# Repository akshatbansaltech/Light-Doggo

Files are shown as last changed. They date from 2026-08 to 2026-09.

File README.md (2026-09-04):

# Light Doggo

Light Doggo is a DIY quadruped robot using 'low cost' BLDC motors.

## Basic Specifications

* RPi 5
* 12x BLDC motors
* Auxiliary board w/LCD display
* 9-axis accelerometer/gyro sensor
* 6s Li-Ion battery, ~72wH

Light Doggo's control system is coded in Python.

# Docs

See the docs directory for a setup guide, bill of materials (BOM), 3D printed parts info, and miscellaneous design notes.

# Development Journal

For a detailed development log with images, see [JOURNAL.md](JOURNAL.md).

# UI

The UI shows the status of the entire system: quadruped joint positions, subsystem status, motor information, inputs, sensors, loop times, etc. The above image shows the simulated quadruped overlapped with real quadruped (based on motor feedback).

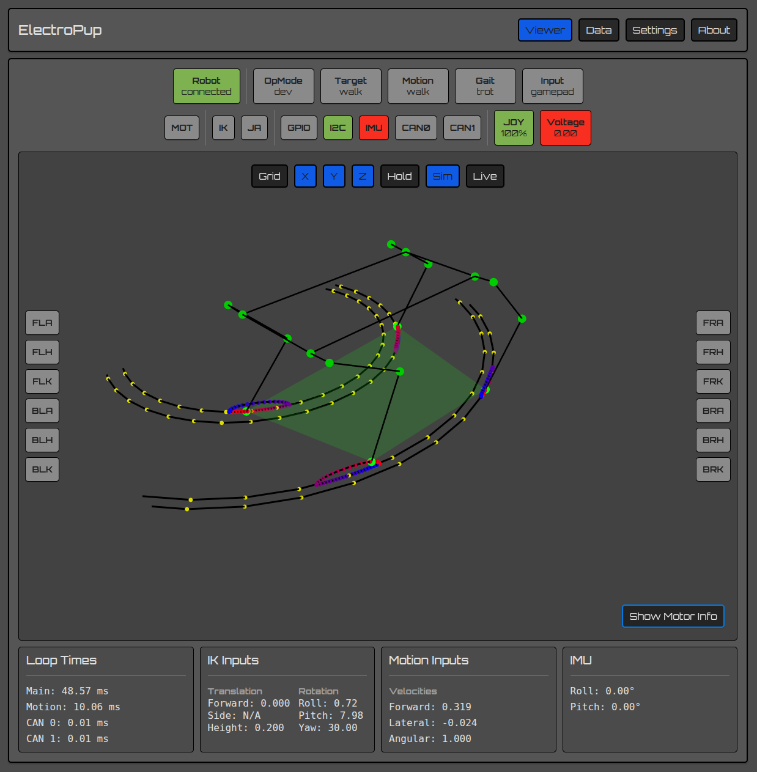
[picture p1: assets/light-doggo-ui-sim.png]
ElectroPup UI Simulation


The above image shows a virtual circle the feet follow to walk in a circle and the bezier curves used for moving the feet up and down.

The UI is built from the React Native Framework using Expo and runs on web. The app will run on Android without the plot. The entire system runs in dev mode so you can run the simulation and UI from a development PC without physical hardware.

# Kinematics

Inverse kinematics, leg position, and gamepad inputs are verified using the UI.

### Trajectories

Bezier curves, sin arcs, and curvature projection are used to generate trajectories. The plots below are examples of control points configurations.

The output of `./src/plot/bezier_curve_plot.py`

Rotation is achieved by projecting a linear trajectory onto a curve. The plots are of example projection calculations.

The output of `./src/plot/projection_plot.py`

# Simulation

Simulation is performed in MuJoCo and can be started by running `./src/sim.sh`. Currently, input controlls are only provided by the gamepad.

The `ElectroPup.xml` currently does not have approximate masses or inertial so the simulated quadruped is rather bouncy.

# Electronics

## PCBs

PCBs are designed in KiCad v8(is compatible with KiCad v10 or higher).

### Power Carrier

The Power Carrier PCB provides a main on/off power switch and distributes power to the motor headers. The Power Carrier creates four CAN bus networks one for each leg. Solder jumpers allow merging the front two legs into a single network and the back two legs into another single network.

### Auxiliary Board

The auxiliary board is optional and not required for the quadruped to operate.

Features:

* Powers RPi via terminal header
* LCD display
* Buzzer (variable pitch)
* NeoPixel strips
* RC Servo channel
* I2C expansion
* Button to control LCD and shutdown Raspberry Pi before power off

Provides direct connection to RPi header for the following breakouts:

* IMU (BNO055 via I2C)
* 4x contact inputs or GPIO
* I2S for sound driver (future barks)
* SBUS to use RC transmitter if BLE gamepad fails in RF congested areas

# Software Architecture

Electropup's software architecture was purposely designed to be simple and to bypass the pain points of using ROS2. A major downside of this single service architecture is needing to sit and stand the quadruped on every software change vs being able to restart individual services quickly without affecting others (i.e. the motors). However, with the simulated quadruped and UI, most development is not performed on a live quadruped.

# Motors

The motors are MG4010E-i10v3 actuators made by LingKong (LKMTECH).

### Specifications

* voltage: 7.4-32V
* communication: CAN 1Mbps
* rated torque: 2.5 N.m
* max torque: 4.5 N.m
* rated current: 3.5 A
* max power: 140 W
* gear ratio: 1:10
* encoders: 18-bit motor, 14-bit reducer
* size: 53mm diameter, 41mm tall

### MG4010E-i10v3 Pros

* easy to use configuration software over non-proprietary USB to UART hardware
* readable CAN bus communication documentation
* small physical size that works well with the desired frame size of ElectroPup
* non-proprietary power/communications connector (JST-ZH 6-POS)

### MG4010E-i10v3 Cons

* configuration software is Windows only
* closed source firmware
* foreign sourced, complicating the warranty process
* CAN unable to configure all parameters
* UART required to configure error thresholds, motor torque limits (for compliance), etc.
* some motors are more difficult to turn by hand and require slightly more operational current

Future projects will prioritize ODrive compatible drivers.

### Motor Zero Positions

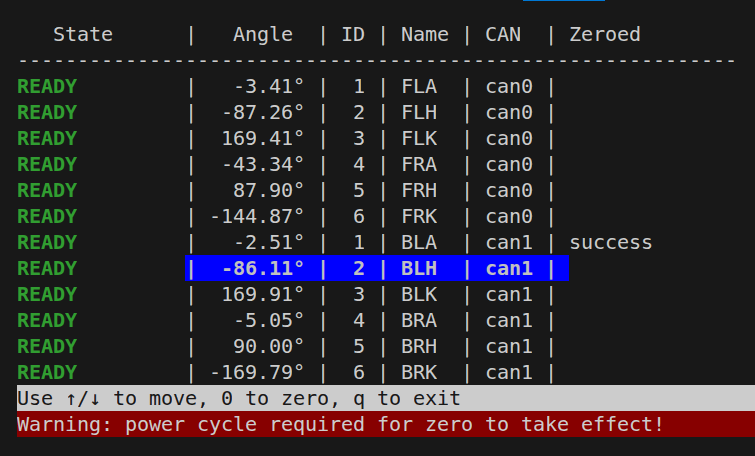
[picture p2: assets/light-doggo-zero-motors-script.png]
Motor Zero Positions


### Motor Tags

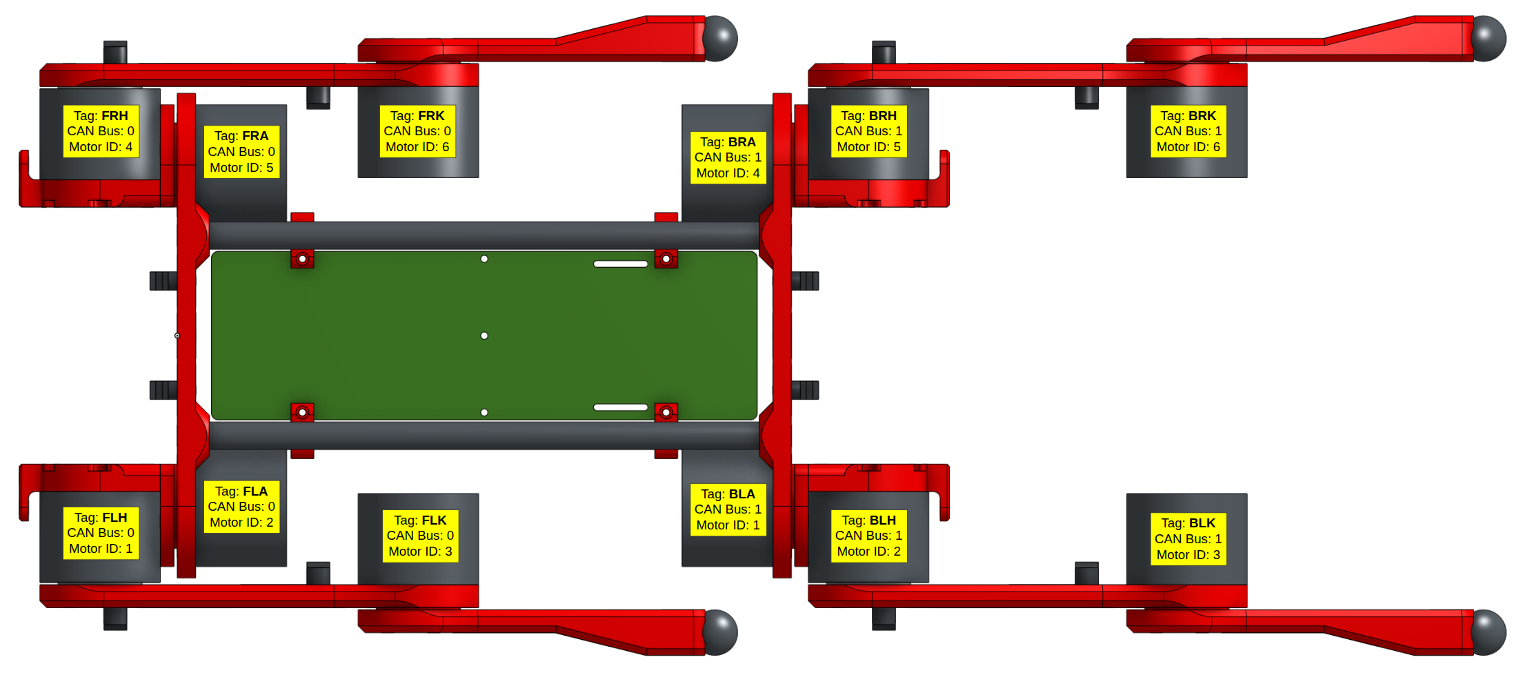
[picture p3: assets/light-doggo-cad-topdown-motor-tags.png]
Motor Tags


### Motor Calibration

The zero-motors.py script is a quick way to verify correct motor configuration and to zero the motors.

Motor Calibration

# CAN Bus

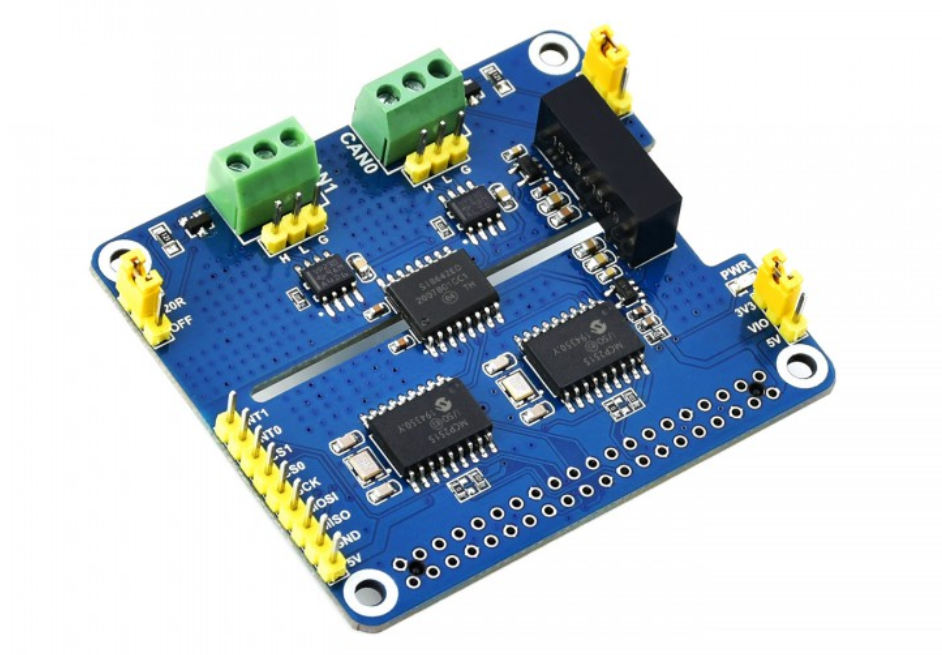
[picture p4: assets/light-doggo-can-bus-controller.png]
CAN Bus Controller


The CAN bus controller is a 2-Channel Isolated CAN Expansion HAT from waveshare.

Each CAN controller drives six motors with an average motor update rate of ~70 Hz. This includes fetching encoder position, setting target angle/speed, and getting error states.

# Gamepad

ElectroPup was coded with a PS4 controller in mind, however xBox, PS5, Logitech gamepads may be used with minor software modifications.

# Environment and IDEs

There are three hardware/software environments described below.

### PC/Laptop - Plotting, Simulation, and Development

Desktop or laptop computer running Ubuntu Desktop (or your preferred flavor of Linux).

Software: VSCode (with remote SSH and PlatformIO extensions), Drawio, LibreOffice, KiCad, OrcaSlicer, Chrome/Firefox

### Raspberry Pi - Quadruped Hardware Driver

The quadruped compute is a Raspberry Pi 5.

The OS is Raspberry Pi OS Lite (Bookworm 64-bit), which is headless, so all development is performed using remote SSH.

### STM32 - Auxiliary Board

An STM32F401 Black Pill dev kit operates the auxiliary board to display the motor and system status on a LCD display and interface with other peripherals such as the buzzer.

Uses VSCode with PlatformIO on the PC/Laptop for development.

# CAD

Parts are modeled using OnShape which provides free web-based full access for non-commercial use. The links below should have export permissions to allow copying the workspace.

* [Assembly](https://cad.onshape.com/documents/b02341d4ebb7f3e9dd488186)
* [Legs](https://cad.onshape.com/documents/6da583196278caf8e90b3122)
* [Body](https://cad.onshape.com/documents/280c24f1b6bdbe8246159786)
* [Hips](https://cad.onshape.com/documents/428031d0c98bf15dcc9f5c8c)
* [Tools](https://cad.onshape.com/documents/3677b35bffbfedb5a3fd2b26)
* [Parts](https://cad.onshape.com/documents/6d4d4e21394ee725ee8ddb38)
* [PCB](https://cad.onshape.com/documents/c8a855826c37bd92b89d9f0e)
* [Neopixels](https://cad.onshape.com/documents/567292ac55c75b2efa25b7d5)

# Battery Pack

The battery is a custom 6S1P Li-Ion using 18650s with a load balancing BMS. The 18650's are Sanyo branded and rated at 3250mAH each providing an estimated 72Wh.

# Future Improvements

This is a general improvement list for future updates or revisions.

* add upside down control (the frame supports walking even after flipped)
* apply IMU for smoother gaits
* add center of mass calculations for smoother gaits
* swap battery and RPi positions for better center of mass
* swap foot lag bolt from SAE to metric
* add curvature to lower leg
* add speaker for barks
* add a tail
* add voltage/current sensor (such as an INA228)
* remove STM32 from aux board and use RPI directly for buzzer, LCD, etc.

# License

This project is licensed under the [MIT License](LICENSE).

# Credits

All the fundings will be allocated by Hack Club.
Thank you Star Dance and Hack Club for their absolute support while making Light Doggo!

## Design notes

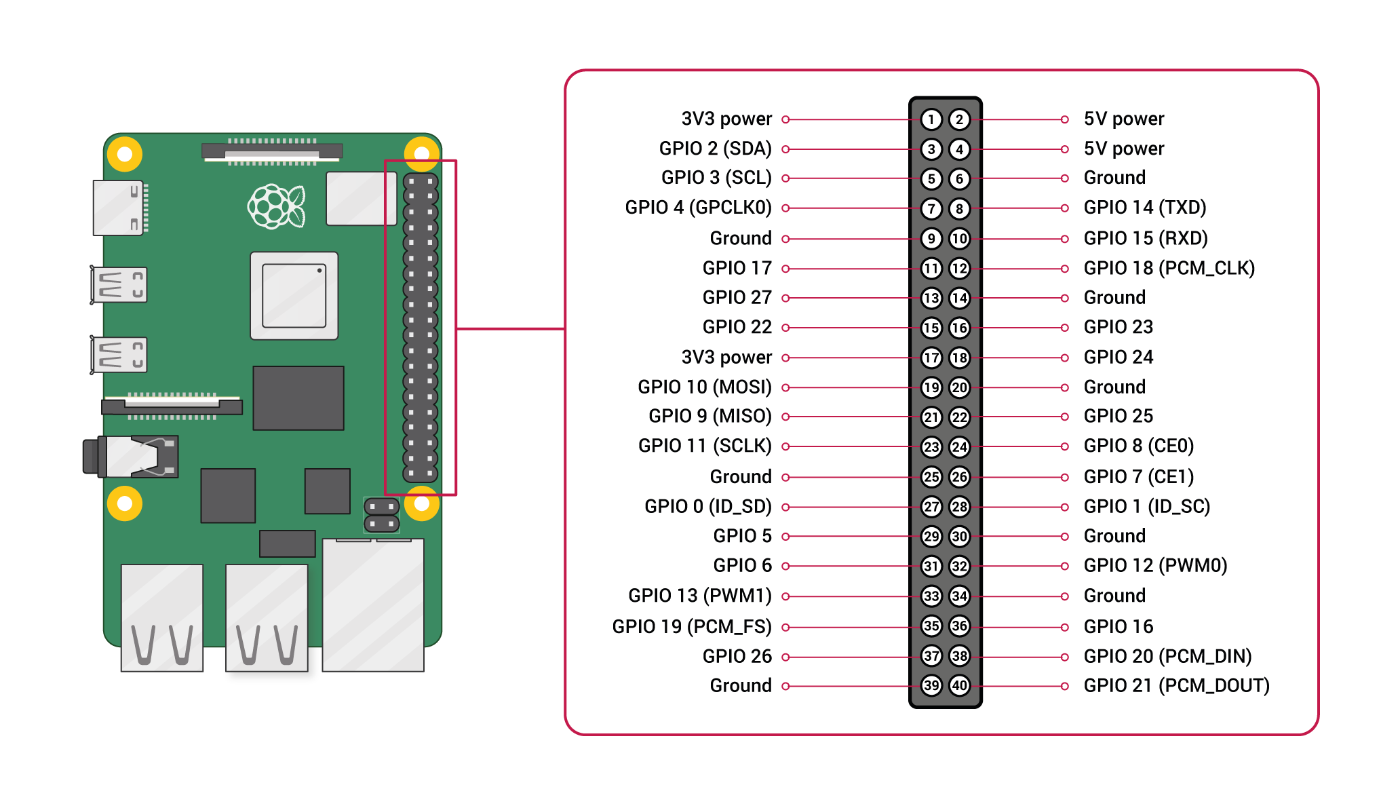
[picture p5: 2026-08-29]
documents/can/RPI-GPIO-Pinout-Diagram.png

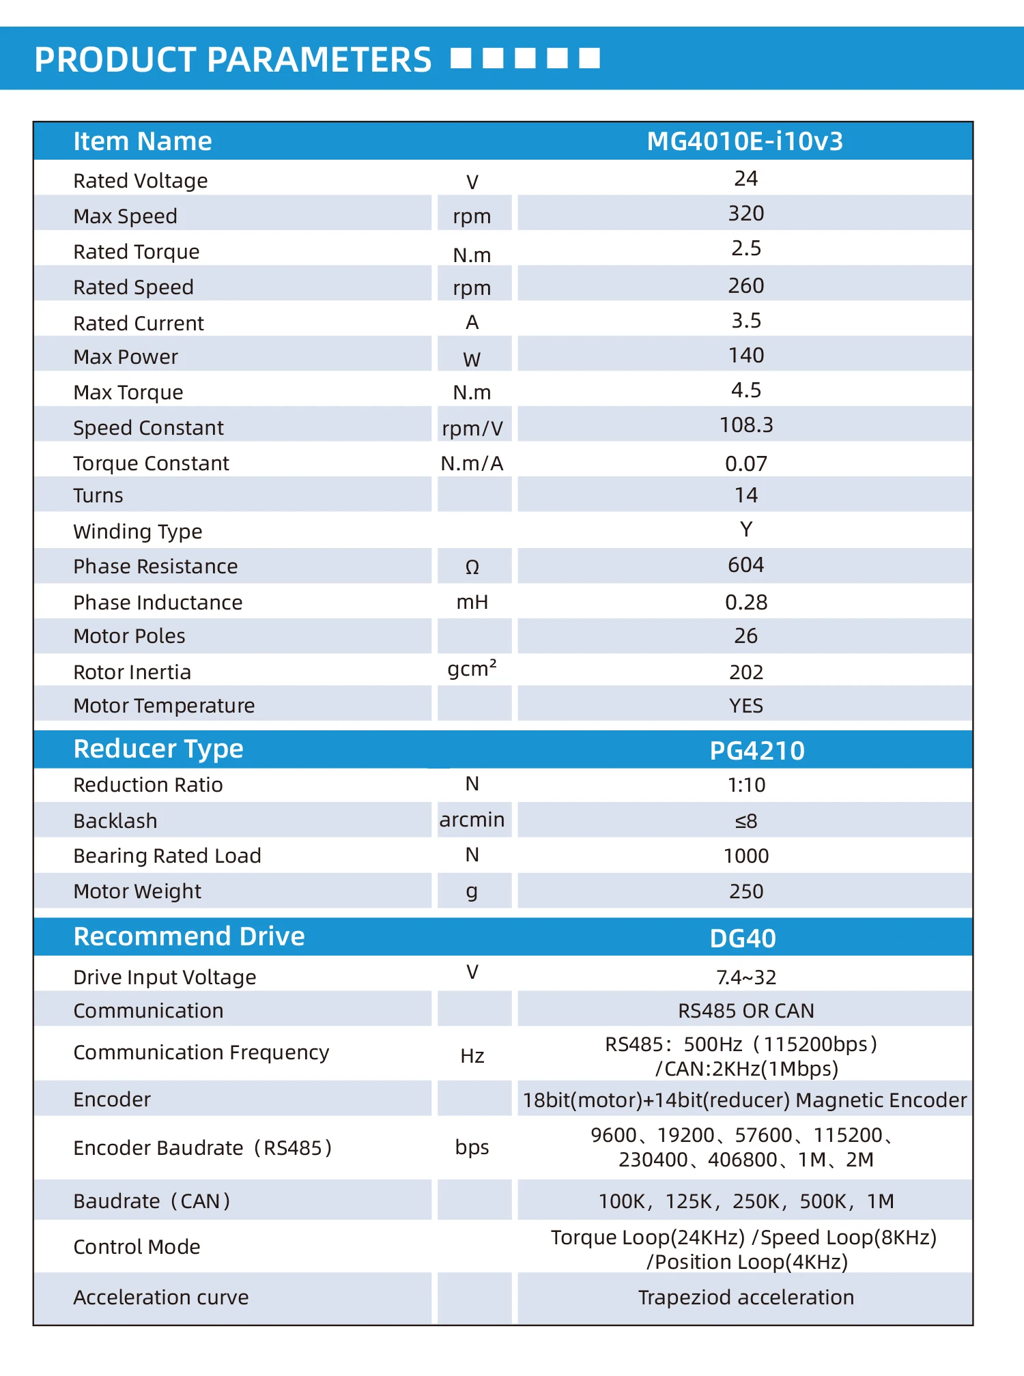
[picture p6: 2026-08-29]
documents/motors/MG4010E-specifications.webp

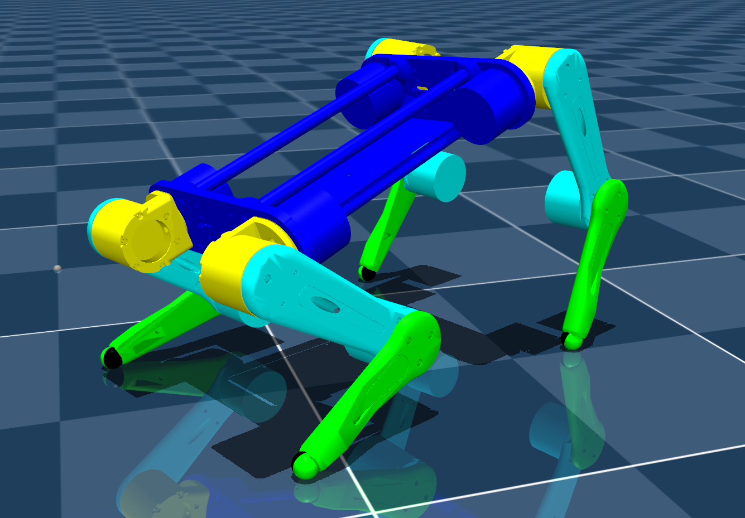
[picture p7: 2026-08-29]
assets/light-doggo-mujuco-simulation-pose.png

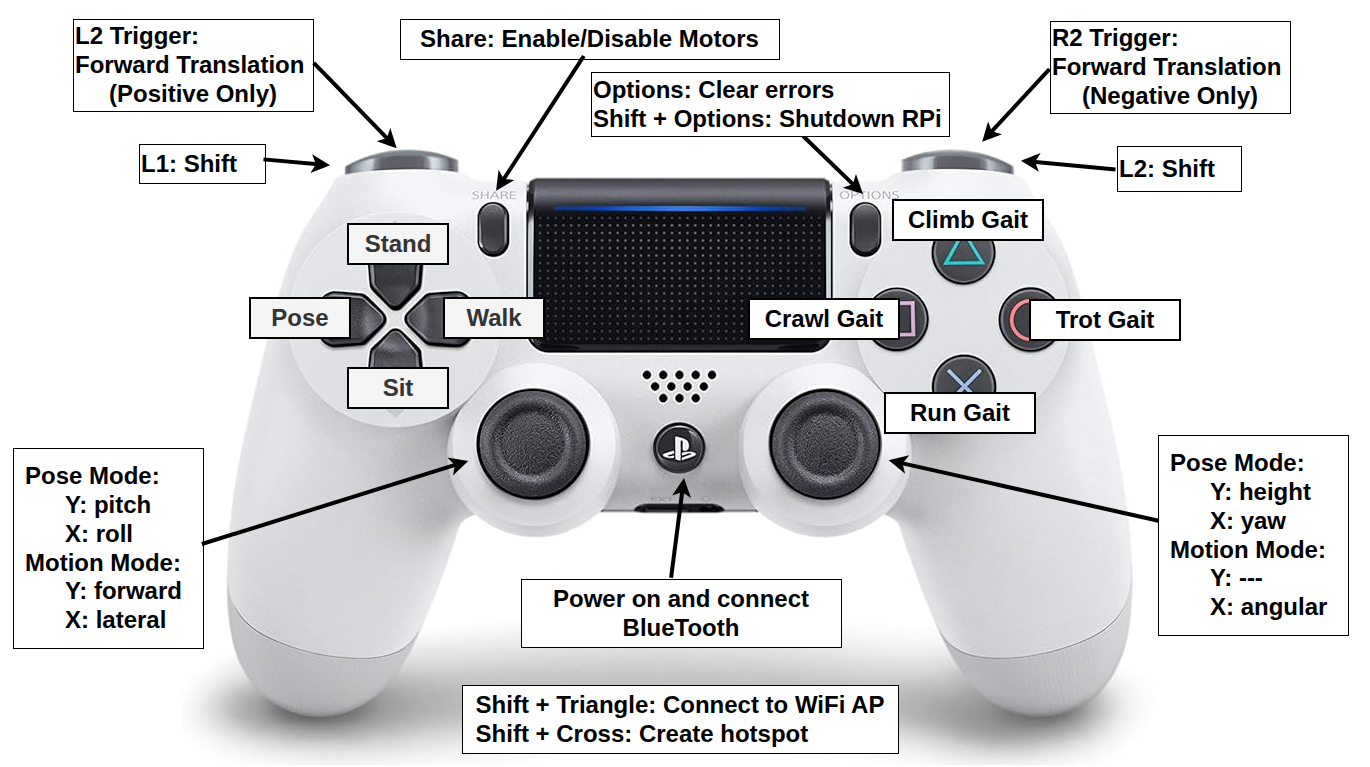
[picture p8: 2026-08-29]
assets/light-doggo-gamepad-controls.png

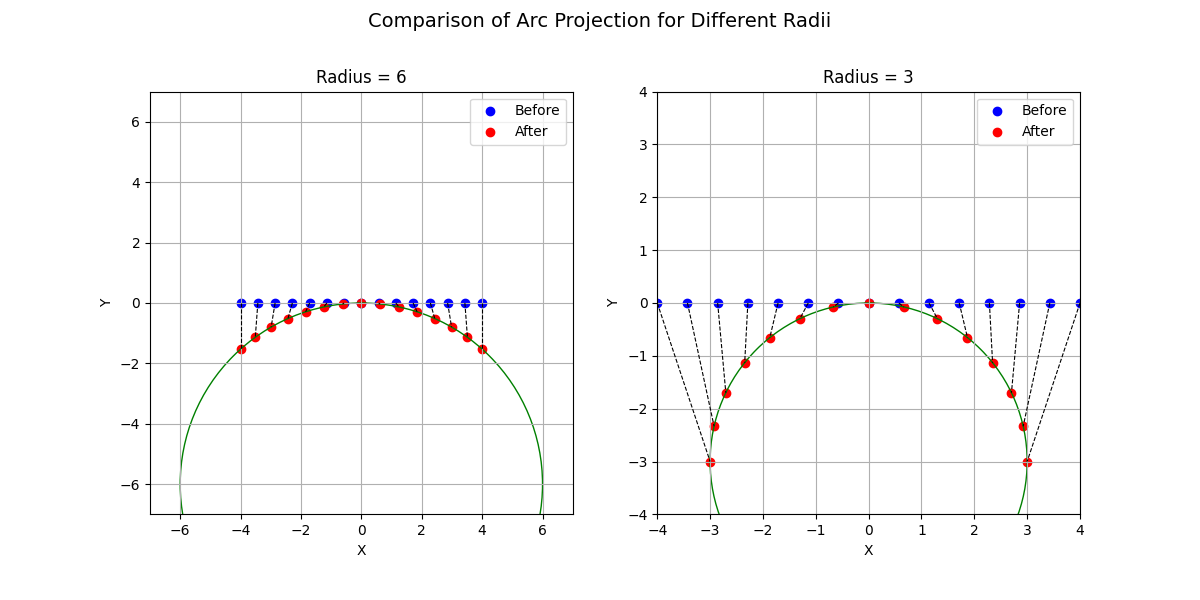
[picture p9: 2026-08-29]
assets/arc-projection-chart.png

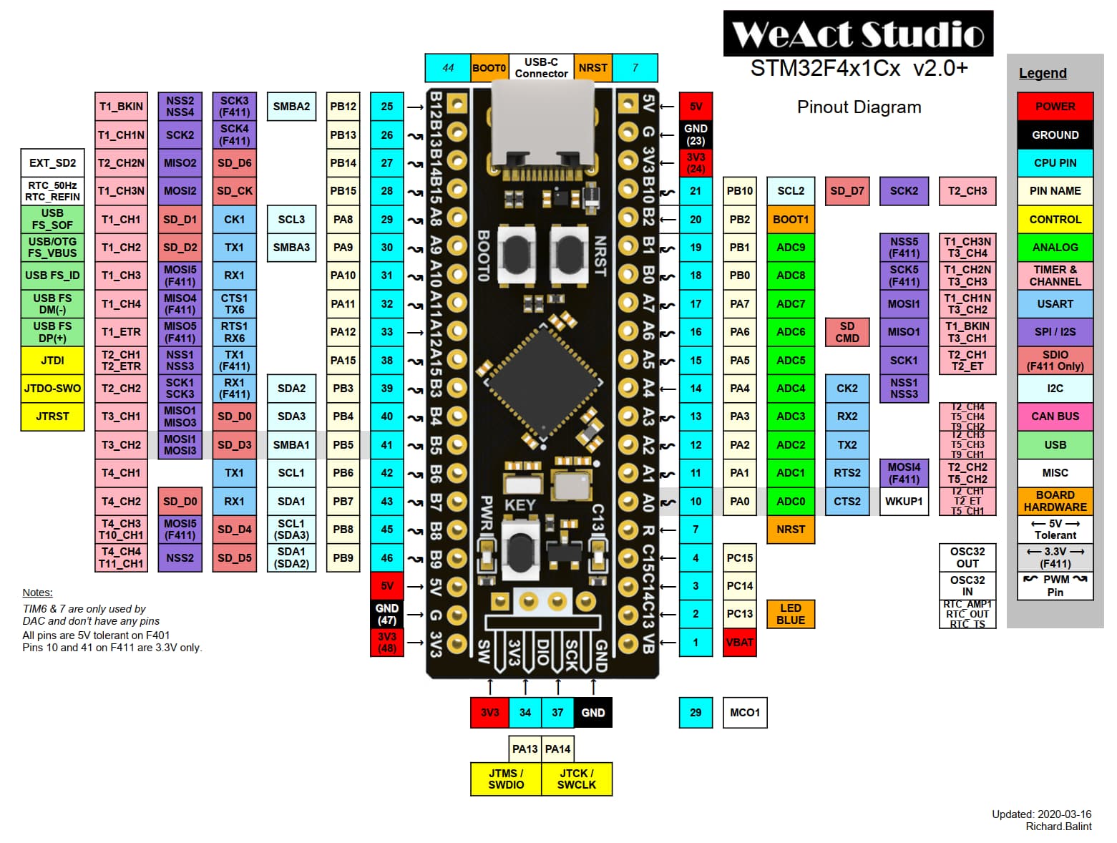
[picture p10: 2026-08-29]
firmware/auxillary/docs/black-pill.jpeg

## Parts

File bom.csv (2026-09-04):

Bill of Materials
Costs are for estimate purposes only and may not include bulk orders, taxes, tariffs, or shipping.
You will always need more parts than the final quantity due to losses and failures.
Links are provided as reference only, carefully review before making purchases.
Hardware | Qty | Est. Cost | SubTotal | Link 1 | Link 2
M2.5x12mm socket head bolt | 24 | 0.05 | 1.2 | mcmaster
M2.5x14mm socket head bolt | 24 | 0.05 | 1.2 | mcmaster
M2.5x40mm socket head bolt | 4 | 0.261 | 1.044 | mcmaster
M3x8mm socket head bolt | 32 | 0.05 | 1.6 | mcmaster
M3x12mm socket head bolt | 4 | 0.05 | 0.2 | mcmaster
M3x14mm socket head bolt | 8 | 0.05 | 0.4 | mcmaster
M3x16mm socket head bolt | 4 | 0.05 | 0.2 | mcmaster
M3x18mm socket head bolt | 24 | 0.05 | 1.2 | mcmaster
M3x20mm socket head bolt | 20 | 0.05 | 1 | mcmaster
M3x25mm socket head bolt | 4 | 0.05 | 0.2 | mcmaster
M5x16mm low-profile bolt | 8 | 0.25 | 2 | amazon | aliexpress
M2.5 nylon lock nut | 4 | 0.1 | 0.4 |  | aliexpress
M3x4mm 4.5mm diameter brass insert | 28 | 0.05 | 1.4 |  | aliexpress
M5x10mm 7mm diameter Brass Insert | 8 | 0.25 | 2 |  | aliexpress
M3x8mm Pin (non-threaded) | 36 | 0.12 | 4.32 |  | aliexpress
1/4-in x 1-in Zinc-Plated Hex-Head Lag Screws | 4 | 0.23 | 0.92 |  | lowes
Frame
Polymaker PolyMax Tough PLA Red - 1.75mm – 750g | 2 | 29.99 | 59.98 | amazon
20mm silicon bead | 4 | 1.38 | 5.52 | aliexpress
Carbon fiber tube 12mm ID x 10mm ID x 254mm | 4 | 5 | 20 | amazon
Electromechanical
MG4010E-i10v3 actuator (CAN version) | 12 | 134 | 1608 | aliexpress
Electronics
PCB: Power Carrier | 1 | 15 | 15
PCB: Auxiliary Board | 1 | 15 | 15
Raspberry Pi 4 | 1 | 55 | 55 | digikey
Micro SD card | 1 | 10 | 10
Waveshare 2-Ch CAN Bus HAT | 1 | 25.99 | 25.99 | amazon | waveshare
40 pin header | 1
40 pin header | 1
Gamepad – PS4 Controller | 1 | 30 | 30
WS2812b strip – 5mm wide, black PCB, 5V | 1 | 4.96 | 4.96 |  | aliexpress
26AWG Silicon wire assorted colors | 1 | 18 | 18 | amazon
Split loom tubing, 7mm OD | 1 | 1.99 | 1.99 |  | aliexpress
STM32 Black Pill dev kit | 1 | 3.07 | 3.07 | amazon | aliexpress
LCD display 128x160 1.8” (HiLetGo) | 1 | 2.45 | 2.45 | amazon | aliexpress
BNO055 IMU Adafruit Layout | 1 | 29.95 | 29.95 | adafruit
2.54mm header low-profile | 1
SWITCH ROCKER SPST 20A 125V | 1 | 1.27 | 1.27 | digikey
DC DC CONVERTER 5V 12W | 1 | 16.91 | 16.91 | digikey
BUZZER MAGNETIC 3V 9MM TH | 1 | 2.04 | 2.04 | https://www.digikey.com/en/products/detail/mallory-sonalert-products-inc/PB-09N23P-03Q/3196328
SWITCH TACTILE SPST-NO 0.05A 24V | 1 | 0.16 | 0.16 | https://www.digikey.com/en/products/detail/te-connectivity-alcoswitch-switches/1825910-6/1632536
IC INVERTER 1CH 1-INP SOT23-5 | 1 | 0.83 | 0.83 | https://www.digikey.com/en/products/detail/texas-instruments/SN74LVC1G14DBVT/1592006
TRANS NPN 40V 0.6A SOT23-3 | 2 | 0.1 | 0.2 | https://www.digikey.com/en/products/detail/onsemi/MMBT2222ALT1G/919593
RES 10K OHM 1% 1/8W 0805 | 12 | 0.02 | 0.24 | https://www.digikey.com/en/products/detail/vishay-dale/CRCW080510K0FKEAC/7928398
RES 1.2K OHM 1% 1/4W 1206 | 1 | 0.1 | 0.1 | https://www.digikey.com/en/products/detail/yageo/RC1206FR-071K2L/728411
RES 500 OHM 1% 1/4W 1206 | 2
LED GREEN CLEAR 1206 SMD | 1 | 0.22 | 0.22 | https://www.digikey.com/en/products/detail/w%C3%BCrth-elektronik/150120GS75000/4489936
TERM BLK 2POS SIDE ENT 3.5MM PCB | 2 | 1.27 | 2.54 | https://www.digikey.com/en/products/detail/molex/0393570002/946543
3-pos JST-ZH header | 5 | 0.161 | 0.805 | https://www.digikey.com/en/products/detail/jst-sales-america-inc/B3B-ZR/926565
4-pos JST-ZH header | 5 | 0.192 | 0.96 | https://www.digikey.com/en/products/detail/jst-sales-america-inc/B4B-ZR/926566
5-pos JST-ZH header | 1 | 0.223 | 0.223 | https://www.digikey.com/en/products/detail/jst-sales-america-inc/B5B-ZR/926567
6-pos JST-ZH header | 12 | 0.195 | 2.34 | https://www.digikey.com/en/products/detail/jst-sales-america-inc/B6B-ZR/926568
3-pos JST-ZH housing | 4 | 0.06 | 0.24 | https://www.digikey.com/en/products/detail/jst-sales-america-inc/ZHR-3/608602
4-pos JST-ZH housing | 1 | 0.075 | 0.075 | digikey
5-pos JST-ZH housing | 1 | 0.054 | 0.054 | digikey
6-pos JST-ZH housing | 8 | 0.131 | 1.048 | digikey
CONN SOCKET 26-28AWG CRIMP TIN | 250 | 0.01888 | 4.72 | digikey
Amass XT30 – male | 1 | 1 | 0.5 | aliexpress | amazon
Battery Pack
18650 Batteries – Sanyo | 8 | 5.99 | 47.92 | 18650batterystore
6s LiPo BMS | 1 | 2.16 | 2.16 |  | aliexpress
Nickel strip | 1 | 9.99 | 9.99 | amazon
Heat shrink wrapper |  |  |  |  | aliexpress
Wire
Amass XT30 – female | 1 | 1 | 0.5 | aliexpress | amazon
Miscellaneous
Zip ties, 2mm width | 1 | 2 | 2
USB-C cable | 1 | 0 | 0 | Junk drawer
18AWG silicon wire – RED | 1 | 2.05 | 2.05 |  | aliexpress
18AWG silicon wire – BLACK | 1 | 2.11 | 2.11 |  | aliexpress
Consumables
super glue
solder
rope/twine
 |  | Total | 1063.82
Tools
3D Printer
Soldering station
Heatset insert tool
Hex driver set
JST crimper
Wire stripper
Wire cutter
Angled needle nose pliers
Measuring tape (metric)
Benchtop power supply
Laptop (for development | KiCad | OnShape | VSCode)
Metric hex key set
Phillips screwdriver
Flathead screwdriver
Flush cutters
Desoldering braid
Flux pen
Multimeter

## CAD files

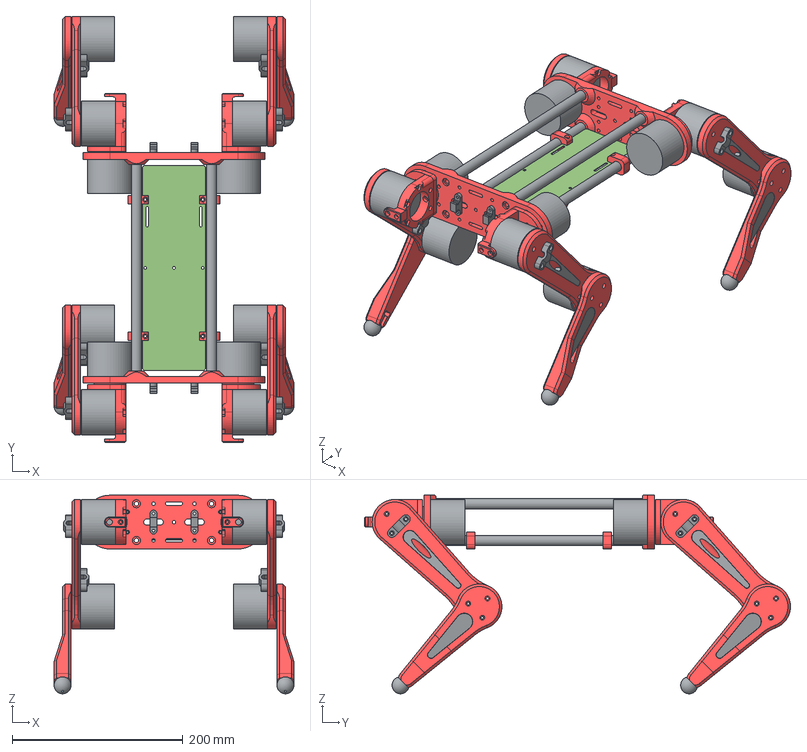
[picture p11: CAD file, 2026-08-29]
cad/3D/assembly-v20.step
281.0 x 499.0 x 232.7 mm
Wire Clamp - Upper Leg - Top x 8
Upper Leg x 4
MG4010E-i10v3 x 12
Accent x 4
Lower Leg - Leg Inteface x 4
Foot - Ball x 4
Leg Accent x 4
Hip Motor Bracket - Base x 4
Hip Motor Bracket - Riser x 4
Hip Wire Clip x 4
Hip Plate x 2
PCB to Tube Clip x 4
Carbon Fiber Tube 12mm OD 10mm ID x 4
Splitloom Clip x 4
PCB Footprint

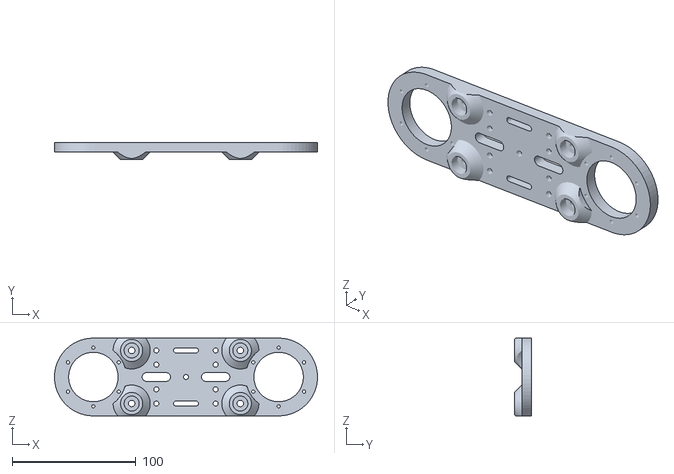
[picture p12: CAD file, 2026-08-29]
cad/3D/v1/hip-plate.stl
212.9 x 14.0 x 63.0

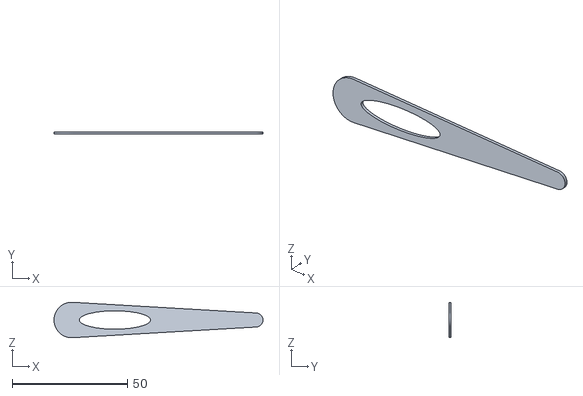
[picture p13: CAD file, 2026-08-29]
cad/3D/v1/upper-leg-accent.stl
90.8 x 1.00 x 15.4

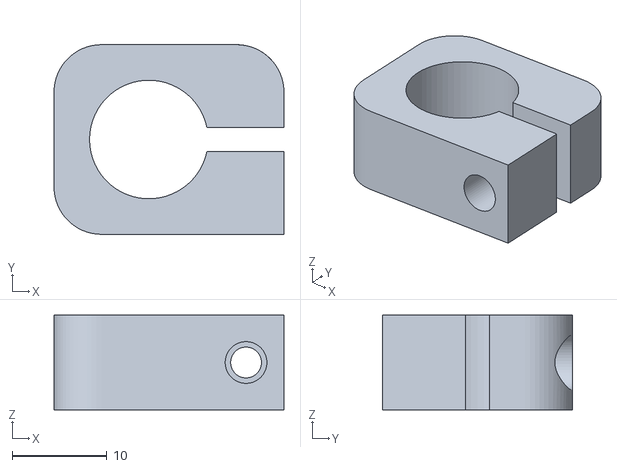
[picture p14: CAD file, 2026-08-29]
cad/3D/v1/pcb-to-tube-clip.stl
24.2 x 20.0 x 10.0

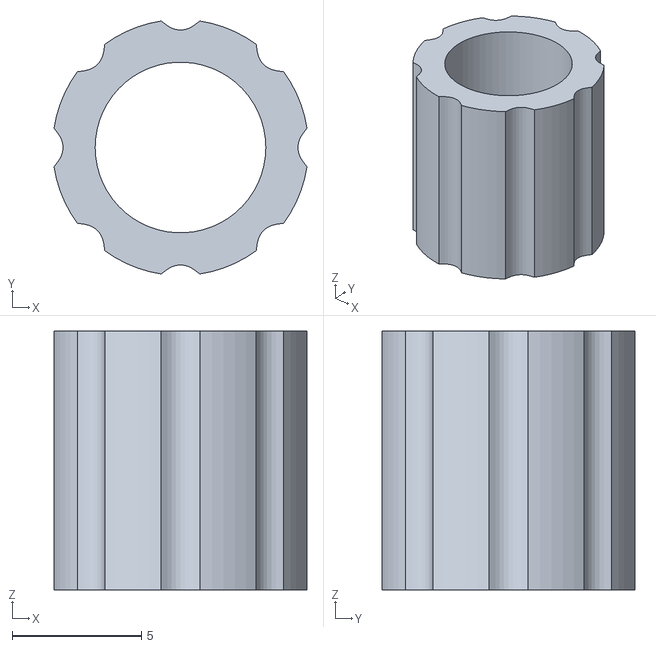
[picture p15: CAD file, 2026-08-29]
cad/3D/v1/carbon-fiber-tube-insert.stl
9.79 x 9.79 x 10.0

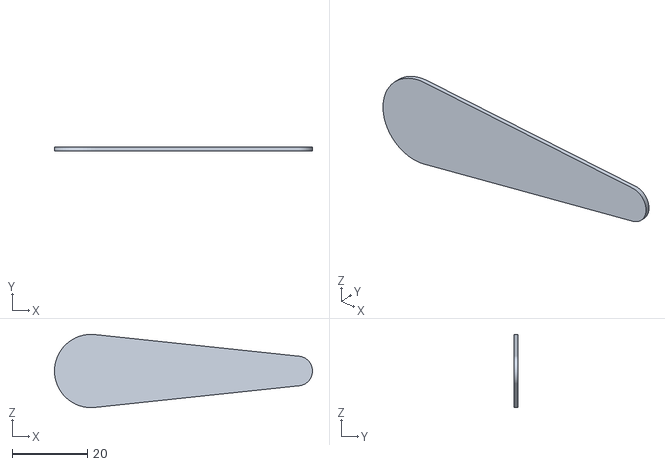
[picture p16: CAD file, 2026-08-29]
cad/3D/v1/lower-leg-accent.stl
68.7 x 1.00 x 19.5

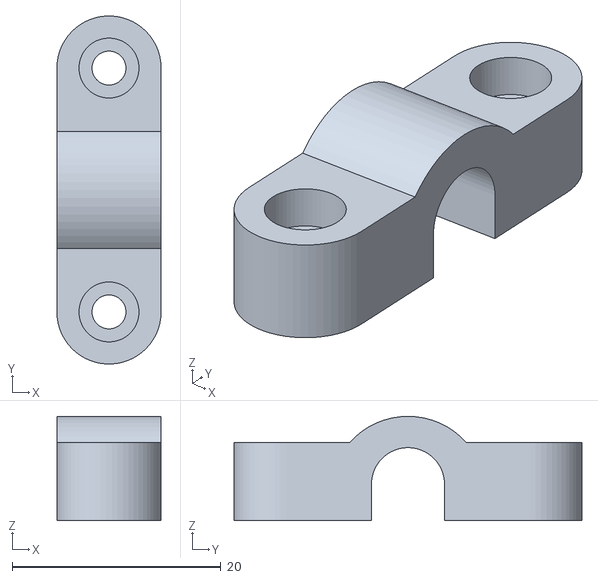
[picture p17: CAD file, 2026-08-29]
cad/3D/v1/splitloom-to-leg-clip.stl
10.0 x 33.4 x 10.0

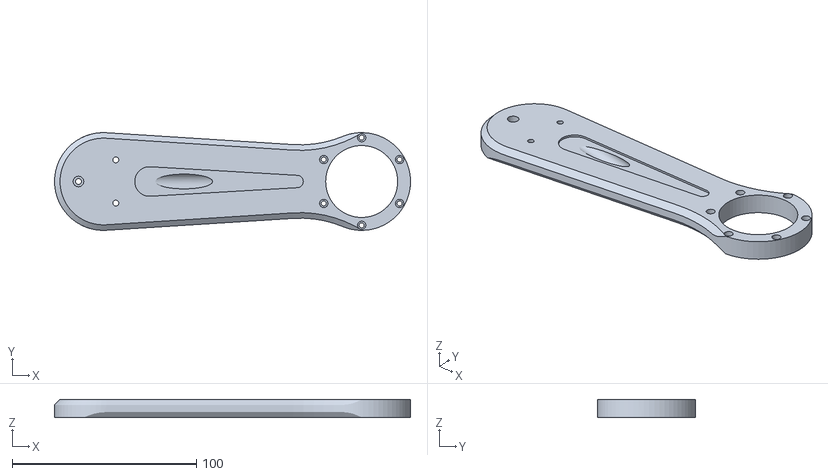
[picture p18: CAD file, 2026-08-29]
cad/3D/v1/upper-leg.stl
193.0 x 53.0 x 10.0

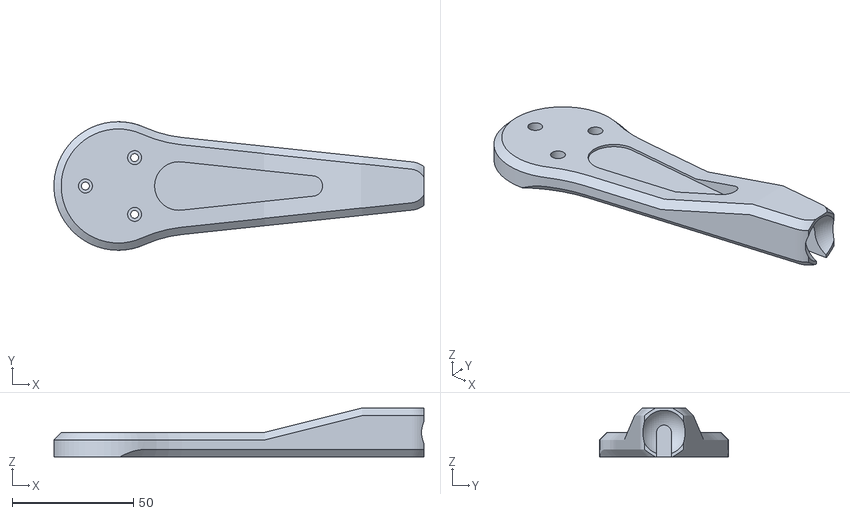
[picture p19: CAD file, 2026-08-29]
cad/3D/v1/lower-leg.stl
152.5 x 53.0 x 20.0

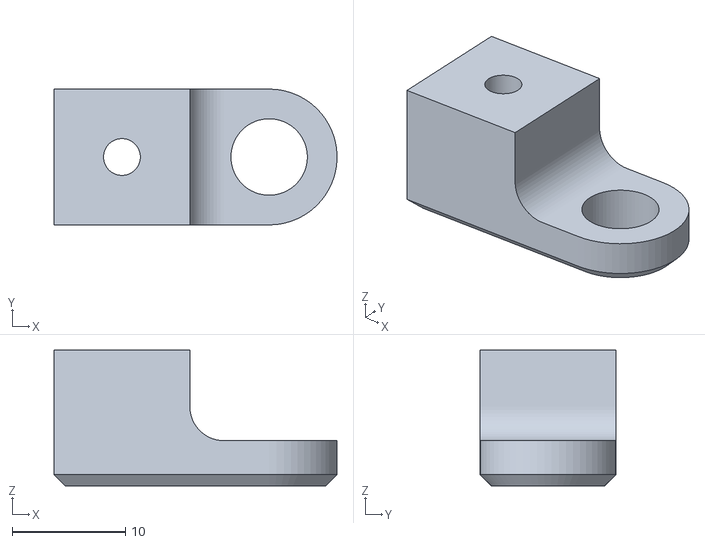
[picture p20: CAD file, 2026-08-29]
cad/3D/v1/hip-wire-clip.stl
25.0 x 12.0 x 12.0

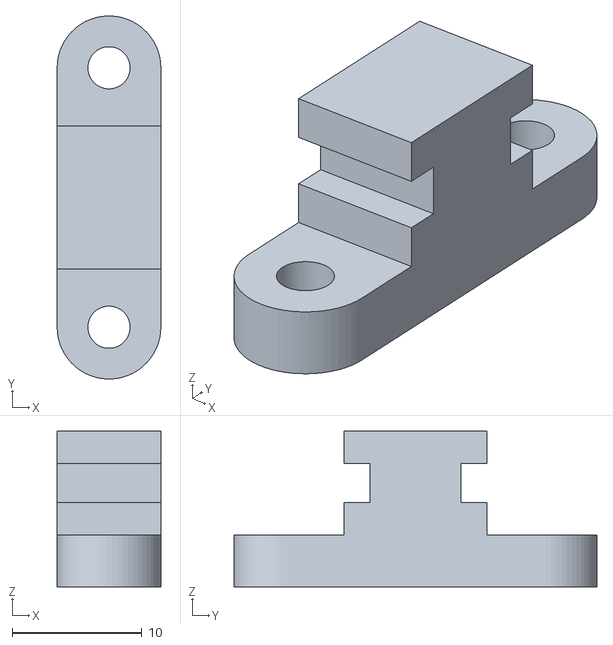
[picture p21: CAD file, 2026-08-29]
cad/3D/v1/splitloom-clip.stl
8.00 x 28.0 x 12.0

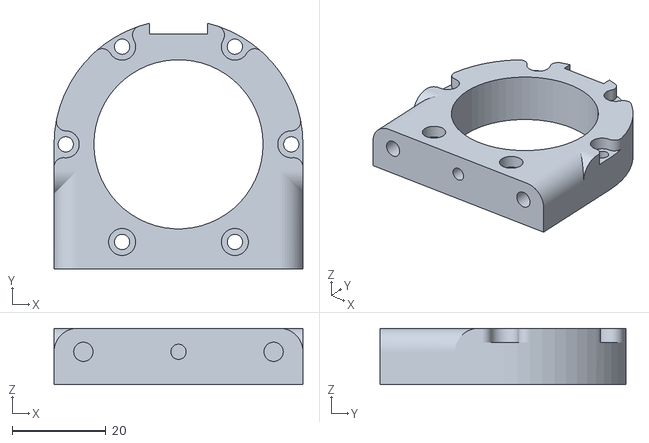
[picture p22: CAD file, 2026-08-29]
cad/3D/v1/hip-motor-bracket-riser.stl
53.0 x 52.3 x 12.0

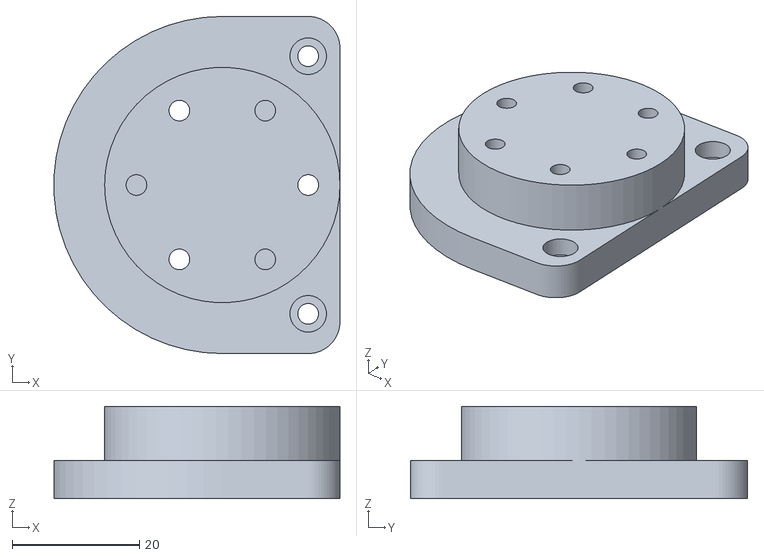
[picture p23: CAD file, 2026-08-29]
cad/3D/v1/hip-motor-bracket-base.stl
45.0 x 53.0 x 14.5

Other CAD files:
cad/2D/light-doggo.dwg

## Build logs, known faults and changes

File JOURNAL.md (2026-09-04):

# Light Doggo — Development Journal

## August 21: Day 0 — Research and finding inspiration

ok, i've been obsessed with quadruped robots for the past few weeks, so today i finally decided to stop just watching videos and actually start building one.

spent basically the whole day going down rabbit holes on YouTube, GitHub, Hackaday, etc. I was trying to figure out what motors people were using, how they were controlling them, and what would actually be realistic for a project that i could afford.

some of the main things i looked into:

* BLDC vs servo vs stepper motors
* Raspberry Pi vs ESP32 vs STM32
* CAN bus for motor communication
* existing open-source quadruped projects
* how other people were doing the leg kinematics

Stanford Pupper was one of the first projects i looked at. The kinematics and overall design are really cool, but the cost is way beyond what i wanted to spend.

then there was SpotMicro, which is much more accessible and open source, but it uses servos. I really wanted to try BLDC motors instead.

eventually i found the LingKong MG4010E motors on AliExpress. They have encoders, CAN communication at 1 Mbps, and around 2.5 N·m of torque. They're about $35 each, so 12 of them would come out to roughly $420.

that's still a lot of money, but honestly not terrible for a 12-DOF quadruped.

for the controller, i decided to go with a Raspberry Pi 5. It's definitely overkill in some ways, but having enough processing power for the control software, UI, simulation, etc. without adding another computer seemed worth it.

by the end of the day, the rough plan was:

* Raspberry Pi 5 as the main computer
* 12 BLDC motors
* CAN bus
* custom PCBs
* Python for the control software
* MuJoCo for simulation

I couldn't find the exact image that originally inspired me, but at this point i had a pretty clear idea of what i wanted to build.

**Time spent: 8 hours**

---

## August 22: Repo setup and renaming everything

today was mostly GitHub/repo cleanup.

I found an existing project that had some really useful stuff in it, especially the KiCad files, firmware structure and CAN bus code. The problem was that it was originally made for a micromouse, so a huge amount of it had absolutely nothing to do with a quadruped.

basically:

```text
git clone upstream-repo
# look through everything
# realise most of it is useless
# delete a ridiculous amount of stuff
# rename everything
```

the maze-solving code, wheel encoders, line sensors, etc. obviously had to go. But the CAN communication code and some of the motor-driver structure were actually really useful.

I probably spent way too long deciding what to keep.

eventually i ended up with something roughly like:

* `firmware/auxillary` — STM32 code for the LCD/auxiliary board
* `pcbs` — KiCad projects
* `cad` — OnShape exports and STLs
* `src/src` — Python control code and simulation
* `docs` — GitHub Pages documentation

using an existing project definitely saved me a lot of time. Writing the entire CAN communication layer from scratch would have been painful.

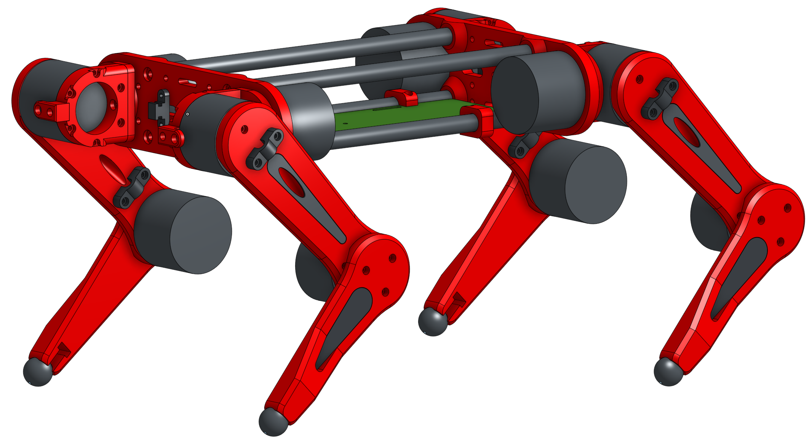
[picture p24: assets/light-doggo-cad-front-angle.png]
Initial CAD render


**Time spent: 6 hours**

---

## August 23: Documentation and CAD

today i realised that if i didn't start documenting things now, i'd probably forget why i made half of the decisions in the first place.

started writing the README and documenting the basic hardware:

* Raspberry Pi 5
* 12 × BLDC motors
* 6S Li-Ion battery
* 9-axis IMU

then somehow the README turned into documenting basically the entire software architecture.

I also made the architecture diagram in Draw.io. It took much longer than i expected, but it actually helped me understand how everything was supposed to fit together.

the current setup has the Python control software talking to the CAN controller, which then communicates with the motors. I'm using four separate CAN networks, basically one per leg. It's probably more complicated than strictly necessary, but it makes things easier to organise.

after that i spent most of the afternoon working on the CAD in OnShape.

the body is basically two plates with mounting points for the Raspberry Pi, battery and electronics. One of the annoying parts was trying to keep everything compact while also keeping the centre of mass reasonably low.

the legs took even longer.

each leg has 3 DOF:

* hip abduction/adduction
* hip flexion/extension
* knee flexion/extension

I had to make custom motor brackets so that the motor axes lined up properly with the joint axes. I used the dimensions from the MG4010E datasheet for this.

it's starting to actually look like a robot now, which is pretty satisfying.

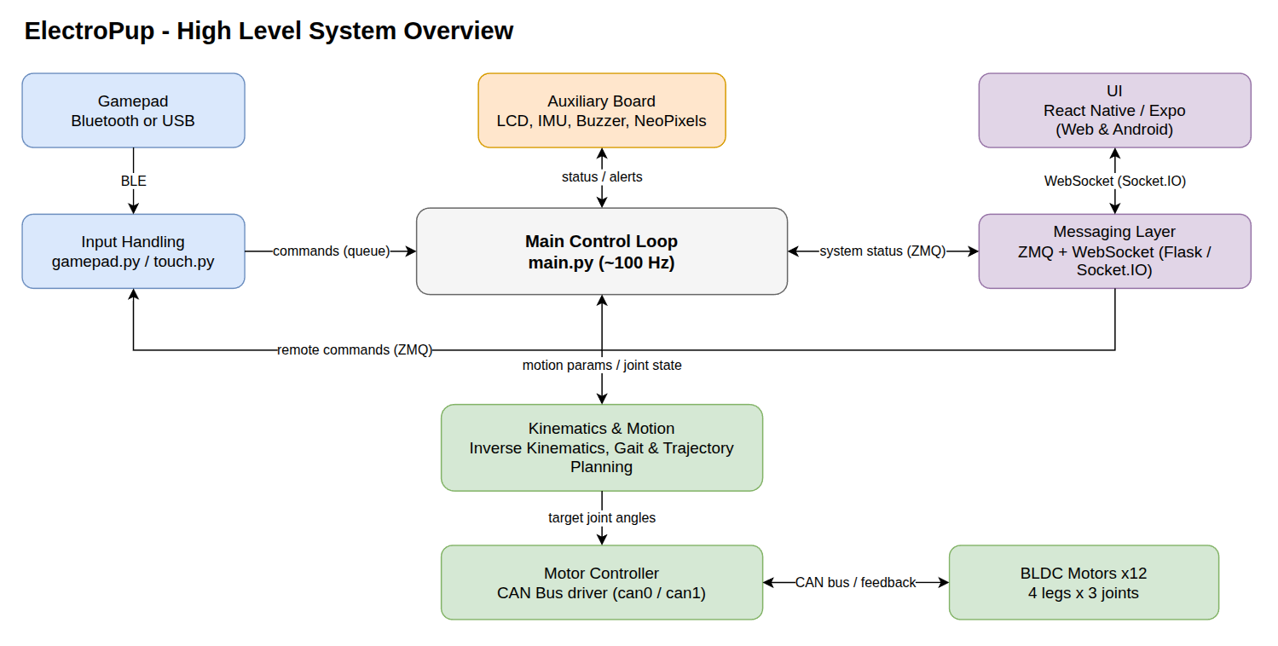
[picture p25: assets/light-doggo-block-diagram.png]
Software architecture diagram


**Time spent: 8 hours**

---

## August 24: PCBs are finally done (hopefully)

the Power Carrier board went through about four revisions today.

the main headache was figuring out how to route power for 12 motors while also fitting four CAN networks onto the board.

I added solder jumpers so that the CAN networks can be combined in different ways. That way, if i don't need all four CAN channels, i can merge some of them instead.

not sure if i'll actually need that flexibility, but i'd rather have the option now than redesign the board later.

the auxiliary board was another story.

originally i thought i'd use an STM32 for basically everything — motor control, LCD, buzzer, neopixels, etc.

then i looked at the Raspberry Pi 5 GPIO/I2C situation again and realised i was making things unnecessarily complicated.

most of that stuff can just be handled directly by the Pi.

so now the STM32 mostly exists to handle the LCD and a few auxiliary functions.

kind of an important lesson from today:

just because i *can* add another microcontroller doesn't mean i should.

one more chip means another firmware project, another communication interface, another thing that can break, and another thing i have to debug.

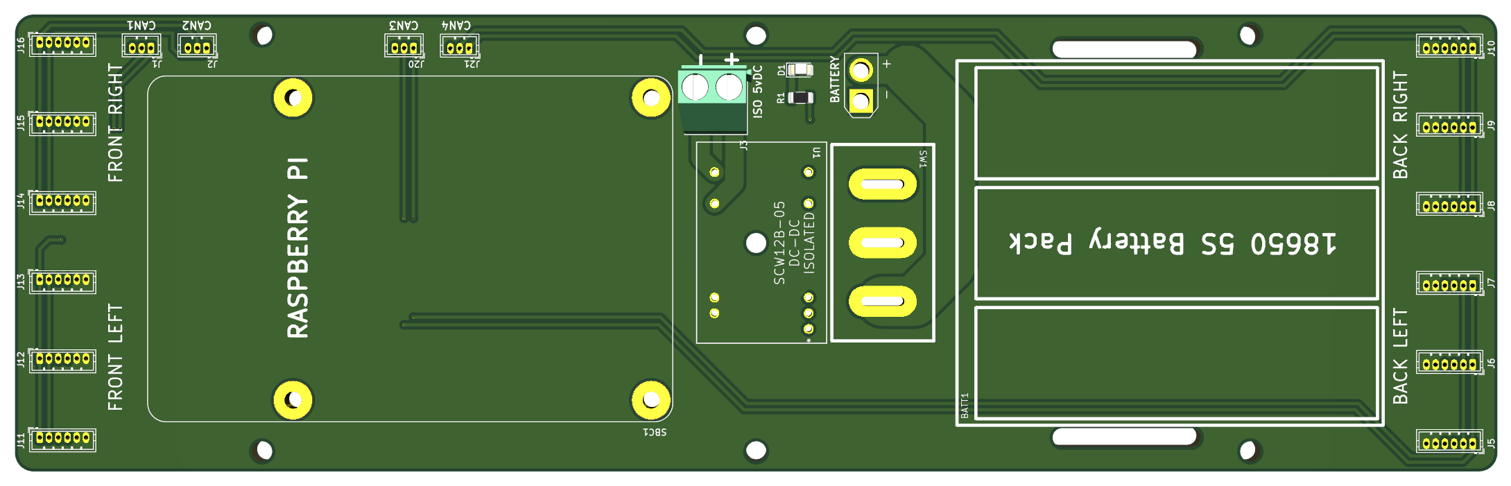
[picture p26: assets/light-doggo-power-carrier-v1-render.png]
Power carrier PCB render


**Time spent: 7 hours**

---

## August 25: KINEMATICS ACTUALLY WORK

today was probably the most satisfying day so far.

I finally got the inverse kinematics working in MuJoCo.

and somehow... it actually looks like a dog walking.

the basic idea is that each leg has three joints, and the inverse kinematics calculates what angles those joints need to be at to put the foot at a particular position.

the difficult part was getting the foot trajectory right.

for straight-line walking i'm using Bezier curves. The control points basically determine how far forward the foot moves and how high it lifts during the swing.

for turning, i'm projecting the normal trajectory onto a curved path. In simple terms, i'm taking the straight walking path and bending it around a circle.

the first version of the simulation was terrible.

the robot was basically bouncing everywhere because i hadn't properly set the masses and inertial properties in the MuJoCo XML. I was using placeholder values, which turned out to be a pretty bad idea.

after fixing those values, things got considerably better. It's still nowhere near perfect, but it can stand and take a few steps without completely losing its mind.

one of the things i really want is to compare the simulated robot with the actual motor feedback. If the simulation and real robot line up, it'll give me a lot more confidence that the kinematics and control code are correct.

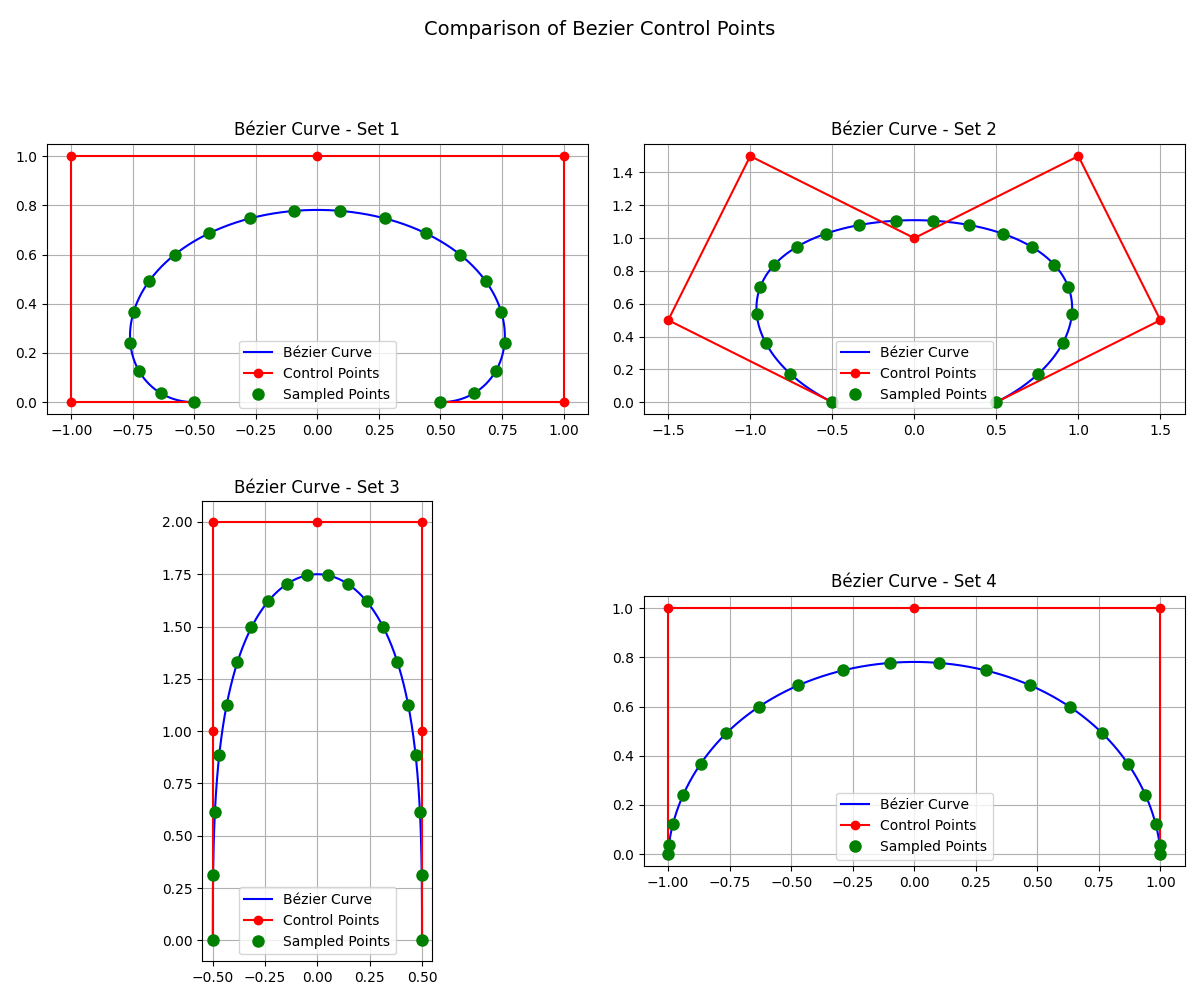
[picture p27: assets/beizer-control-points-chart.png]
Bezier curve control points


**Time spent: 8 hours**

---

## August 26: The UI is finally useful

the UI is finally at the point where i can actually use it for debugging instead of just looking pretty.

it's built with React Native + Expo and currently shows:

* joint positions
* motor currents
* sensor data
* control-loop timing
* gamepad inputs
* motor feedback

the coolest part is probably the 3D visualisation.

I can display the simulated quadruped and the real motor feedback at the same time, so i can actually see whether the robot is doing what the control software thinks it's doing.

I initially wanted to push all the motor feedback at full speed, but that made the WebSocket connection pretty unhappy.

connections kept dropping whenever too much data was being sent.

eventually i throttled the motor feedback to around 50 Hz. That seems to be a much better compromise.

the app runs on the web through Expo while i'm developing, which is really convenient because i don't have to keep deploying it to my phone every time i change something.

Android will work too, although the 3D visualisation is limited because WebGL support isn't as nice there.

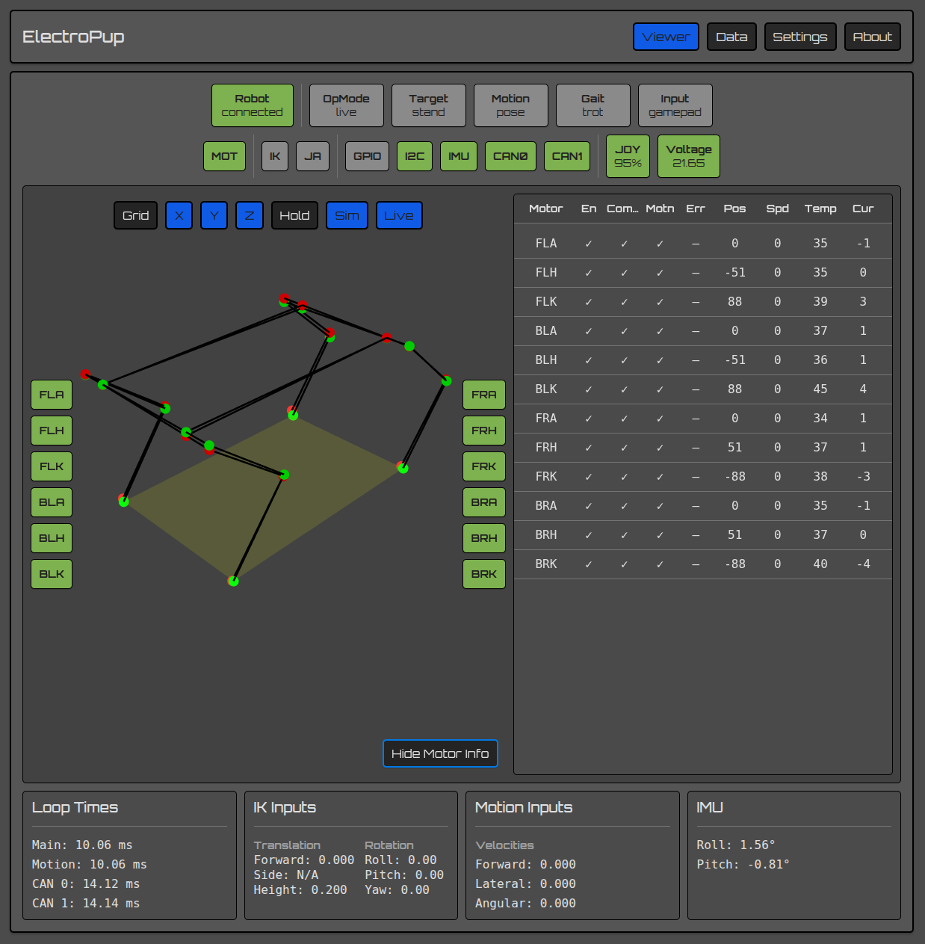
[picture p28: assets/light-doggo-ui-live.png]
Live UI with motor data


**Time spent: 6 hours**

---

## August 27: Firmware and website

today was mostly firmware.

got the STM32 firmware compiling and running on the Black Pill dev board.

the auxiliary board is responsible for things like:

* powering the Raspberry Pi
* LCD
* buzzer
* neopixels

the LCD was probably the most annoying part.

it's an SPI display, so actually sending data isn't too difficult. The annoying part was the initialisation sequence. There are a bunch of register writes that have to happen in the right order before the display actually works.

I found a reference implementation in an Adafruit library and adapted it instead of trying to figure out the entire LCD controller from scratch.

the buzzer was much easier. It's just PWM, although i added variable pitch so it can play different tones.

eventually i'd like to make it do some kind of bark sound because obviously a robot dog needs to bark.

also got the GitHub Pages site set up and added the BOM.

the current estimated cost is around $700 for the whole robot.

that's definitely not cheap, but considering it's a 12-DOF quadruped with custom PCBs, BLDC motors, sensors and a Raspberry Pi, i'm pretty happy with it.

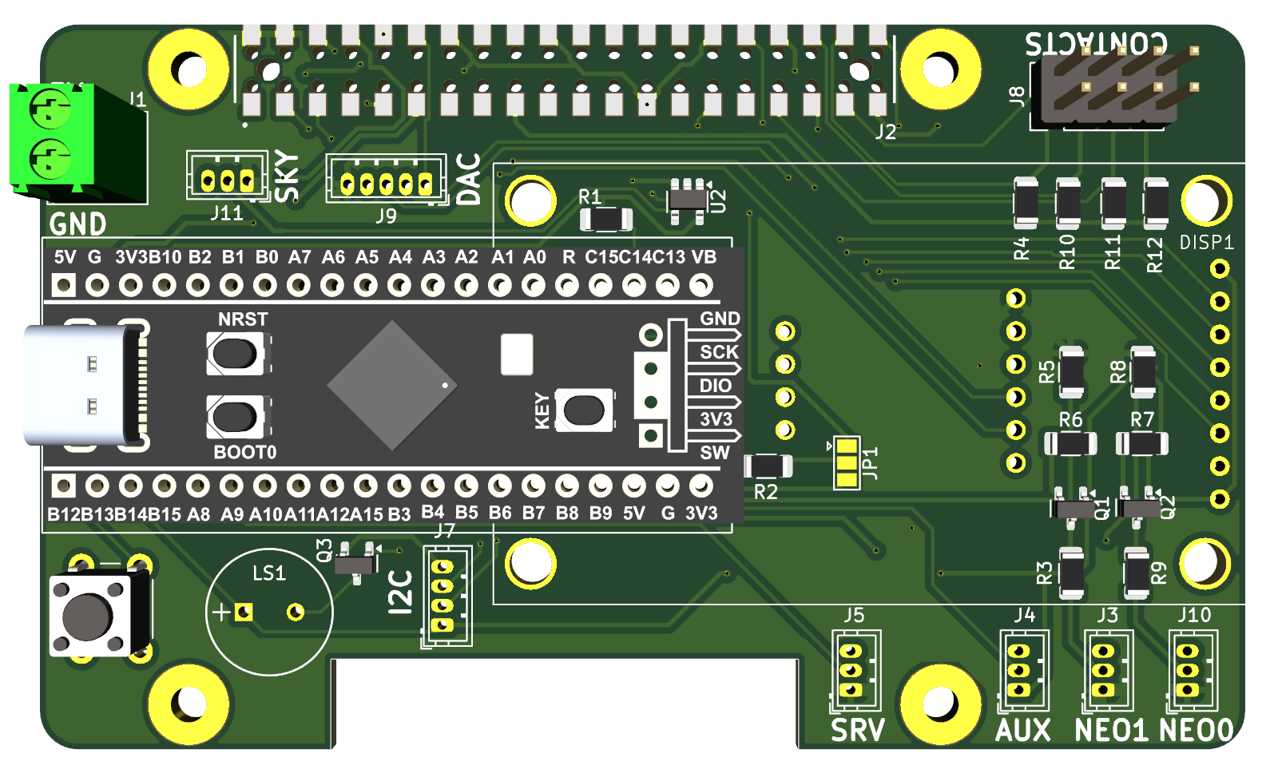
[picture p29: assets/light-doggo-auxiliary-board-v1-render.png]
Auxiliary board render


**Time spent: 7 hours**

---

## August 28: Cleanup and final polish

today was mostly boring stuff, but necessary boring stuff.

first, i switched the project license from Apache 2.0 to MIT.

the main reason was just simplicity. For a small personal open-source project, MIT seemed easier to understand and maintain.

then i cleaned up the README and fixed some weird character encoding problems that were making some things render incorrectly on GitHub.

also discovered that KiCad had dumped a bunch of backup files and other generated files into the repo.

so yeah, spent a while cleaning those up and adding things to `.gitignore`.

I also finished a few documentation sections:

* motor calibration
* gamepad controls
* wiring
* setup instructions
* demo

the motor calibration script, `zero-motors.py`, is probably one of the more useful little tools in the repo. It connects to the motors over CAN, reads their current encoder positions and lets me set their zero offsets.

finally added the wireframe demo GIF too.

it's only the simulation walking in a circle, but honestly it looks pretty cool.

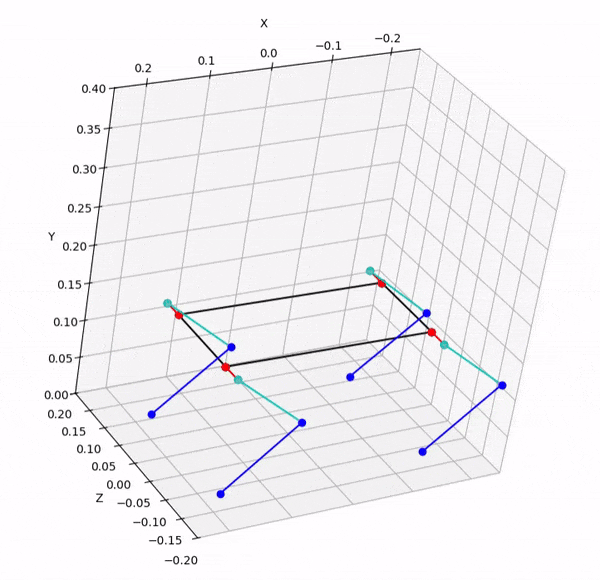
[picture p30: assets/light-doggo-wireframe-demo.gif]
Wireframe demo


and that's basically the first development sprint done.

there's still a ridiculous amount left to do — especially getting the real robot walking reliably — but at least at this point Light Doggo isn't just an idea and some CAD files anymore.

**Time spent: 6 hours**

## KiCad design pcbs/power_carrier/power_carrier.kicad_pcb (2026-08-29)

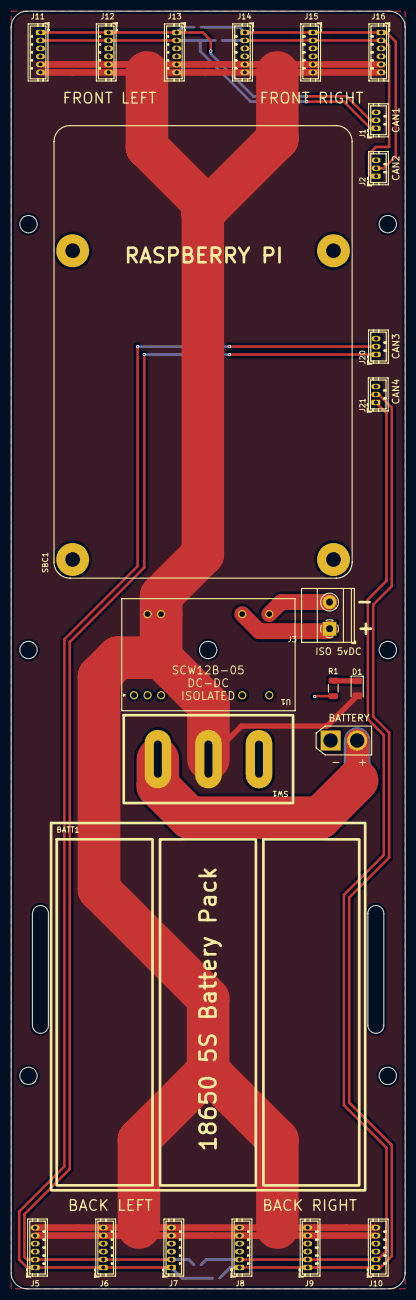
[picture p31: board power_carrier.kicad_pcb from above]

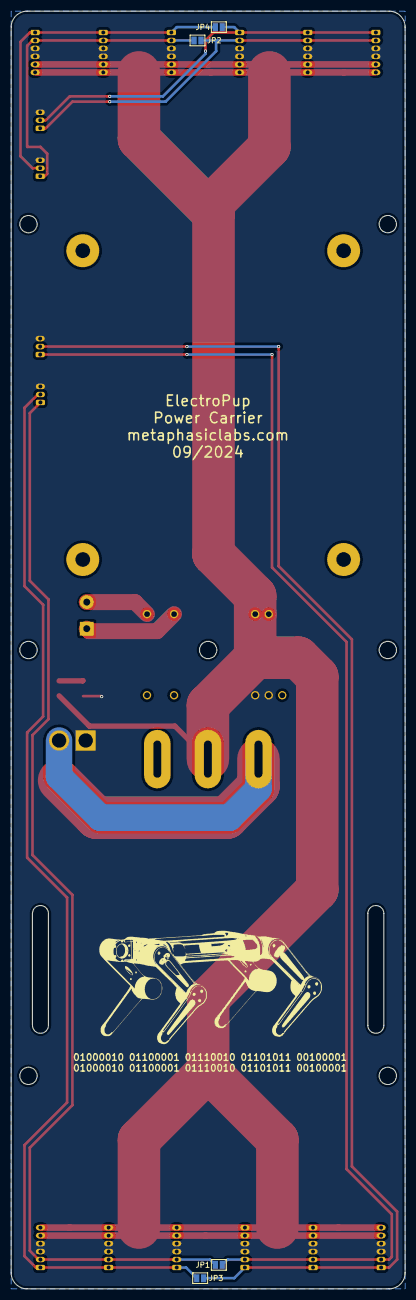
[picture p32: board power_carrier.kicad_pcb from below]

Board: 2 copper layers, 74.0 x 240.0 mm, 28 parts (4 on the bottom side), 14 nets.

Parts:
BATT1: 18650 6S Battery Pack - Footprint Only
D1: LED; LED_1206_3216Metric
J1, J2, J20, J21: Conn_01x03; JST_ZH_B3B-ZR_1x03_P1.50mm_Vertical
J3: Conn_01x02; TerminalBlock_Phoenix_MKDS-1,5-2_1x02_P5.00mm_Horizontal
J4: AMASS Connector; AMASS_XT30U-M_1x02_P5.0mm_Vertical
J5, J6, J7, J8, J9, J10, J11, J12, J13, J14, J15, J16: Conn_01x06; JST_ZH_B6B-ZR_1x06_P1.50mm_Vertical
JP1, JP2, JP3, JP4: SolderJumper_2_Open; SolderJumper-2_P1.3mm_Open_Pad1.0x1.5mm
R1: R_Small_US; R_1206_3216Metric
SBC1: RASPBERRY_PI_4B - Footprint Only
SW1: SW_SPST; CRE22F4DBBNE
U1: SCW12B-05; SCW12B-05_MWU

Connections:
+BATT: D1.2 (A), J5.5, J5.6, J6.5, J6.6, J7.5, J7.6, J8.5, J8.6, J9.5, J9.6, J10.5, J10.6, J11.5, J11.6, J12.5, J12.6, J13.5, J13.6, J14.5, J14.6, J15.5, J15.6, J16.5, J16.6, SW1.2 (B), U1.22 (+VIN), U1.23 (+VIN)
/CAN1 HIGH: J1.1, J11.2, J12.2, J13.2, JP2.1 (A)
/CAN1 LOW: J1.2, J11.1, J12.1, J13.1, JP4.1 (A)
/CAN2 HIGH: J2.1, J14.2, J15.2, J16.2, JP2.2 (B)
/CAN2 LOW: J2.2, J14.1, J15.1, J16.1, JP4.2 (B)
/CAN3 HIGH: J5.2, J6.2, J7.2, J20.1, JP1.1 (A)
/CAN3 LOW: J5.1, J6.1, J7.1, J20.2, JP3.1 (A)
/CAN4 HIGH: J8.2, J9.2, J10.2, J21.1, JP1.2 (B)
/CAN4 LOW: J8.1, J9.1, J10.1, J21.2, JP3.2 (B)
/ISO 5vDC GND: J3.2, U1.14 (+VOUT)
/ISO 5vDC+: J3.1, U1.16 (-VOUT)
GND: J1.3, J2.3, J4.1 (-), J5.3, J5.4, J6.3, J6.4, J7.3, J7.4, J8.3, J8.4, J9.3, J9.4, J10.3, J10.4, J11.3, J11.4, J12.3, J12.4, J13.3, J13.4, J14.3, J14.4, J15.3, J15.4, J16.3, J16.4, J20.3, J21.3, R1.2, U1.2 (-VIN), U1.3 (-VIN)
unnamed: D1.1 (K), R1.1
unnamed: J4.2 (+), SW1.1 (A)

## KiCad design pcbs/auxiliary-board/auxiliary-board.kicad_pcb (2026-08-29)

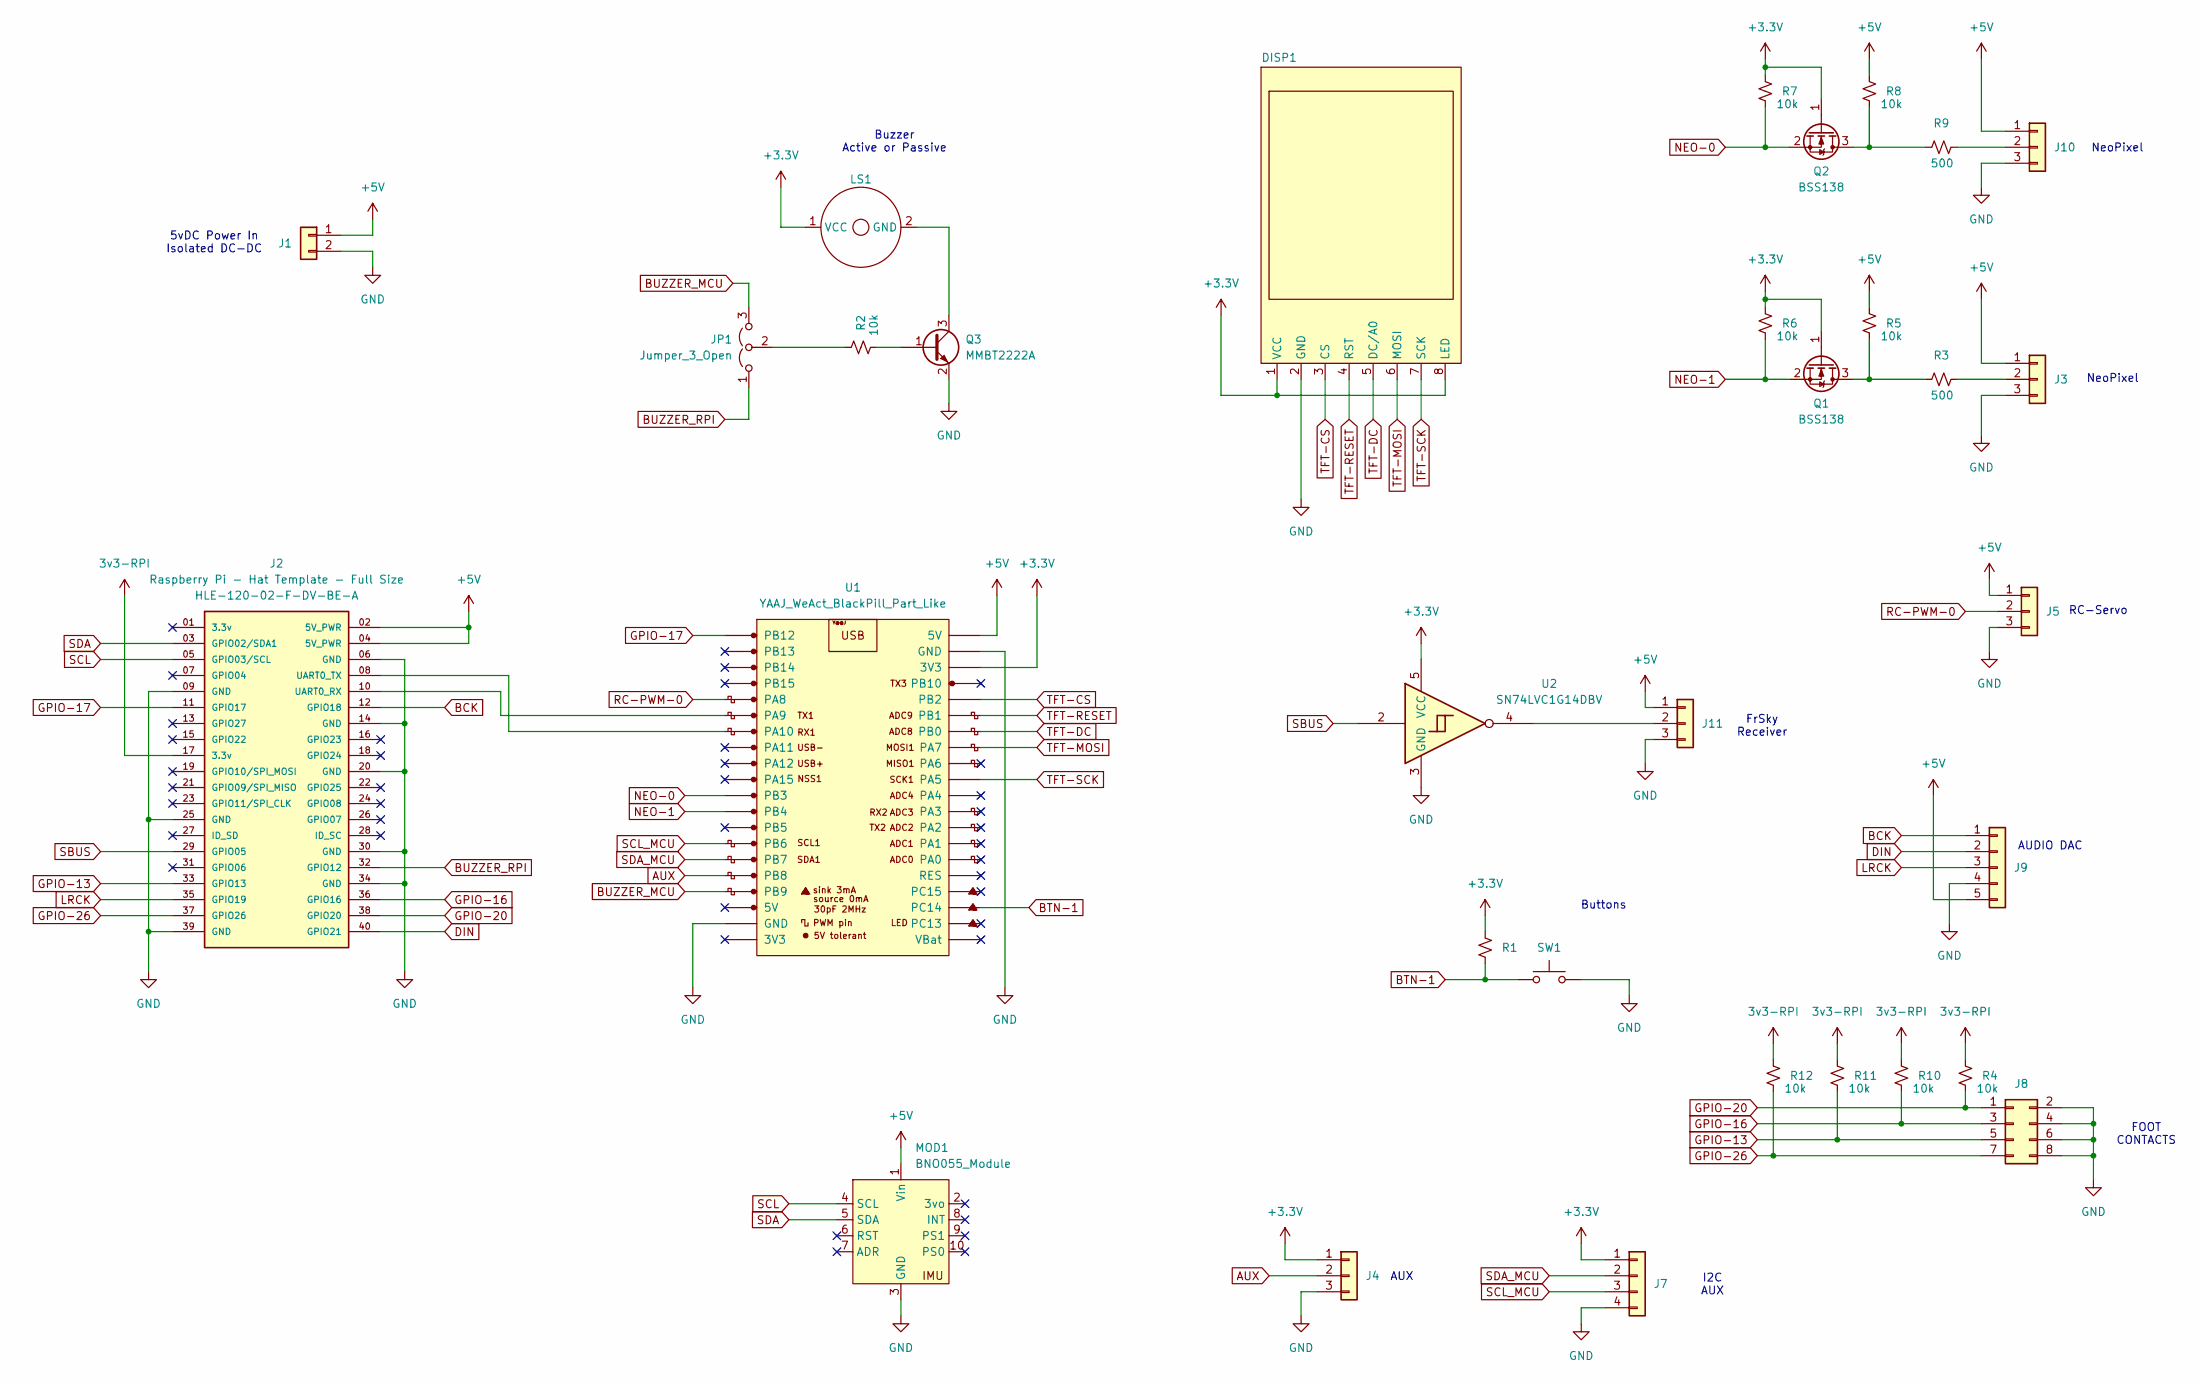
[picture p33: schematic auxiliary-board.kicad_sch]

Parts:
DISP1: LCD-Display-1.8-128x160-Hiletgo
J1: Conn_01x02; TerminalBlock_Phoenix_PT-1,5-2-3.5-H_1x02_P3.50mm_Horizontal
J2: Raspberry Pi - Hat Template - Full Size; Raspberry Pi - Hat Template - Full Size Extended
J3, J4, J5, J10, J11: Conn_01x03; JST_ZH_B3B-ZR_1x03_P1.50mm_Vertical
J7: Conn_01x04; JST_ZH_B4B-ZR_1x04_P1.50mm_Vertical
J8: Conn_02x04_Odd_Even; PinHeader_2x04_P2.54mm_Vertical
J9: Conn_01x05; JST_ZH_B5B-ZR_1x05_P1.50mm_Vertical
JP1: Jumper_3_Open; SolderJumper-3_P1.3mm_Open_Pad1.0x1.5mm
LS1: PB-09N23P-03Q_MAL
MOD1: BNO055_Module; BNO055 Module
Q1, Q2: BSS138; SOT-23
Q3: MMBT2222A; SOT-23
R1: R_Small_US; R_1206_3216Metric
R2, R4, R5, R6, R7, R8, R10, R11, R12: 10k; R_1206_3216Metric
R3, R9: 500; R_1206_3216Metric
SW1: SW_Push; SW_PUSH_6mm_H4.3mm
U1: YAAJ_WeAct_BlackPill_Part_Like; Blackpill WeAct
U2: SN74LVC1G14DBV; SOT-23-5

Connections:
3v3-RPI: J2.17 (3.3v), R4.2, R10.2, R11.2, R12.2
+3.3V: DISP1.1 (VCC), DISP1.8 (LED), J4.1, J7.1, LS1.1 (VCC), Q1.1 (G), Q2.1 (G), R1.2, R6.2, R7.2, U1.38 (3V3), U2.5 (VCC)
+5V: J1.1, J2.02 (5V_PWR), J2.04 (5V_PWR), J3.1, J5.1, J9.5, J10.1, J11.1, MOD1.1 (Vin), R5.2, R8.2, U1.40 (5V)
AUX: J4.2, U1.16 (PB8)
BCK: J2.12 (GPIO18), J9.1
BTN-1: R1.1, SW1.1, U1.23 (PC14)
BUZZER_MCU: JP1.3 (B), U1.17 (PB9)
BUZZER_RPI: J2.32 (GPIO12), JP1.1 (A)
DIN: J2.40 (GPIO21), J9.2
GND: DISP1.2 (GND), J1.2, J2.06 (GND), J2.09 (GND), J2.14 (GND), J2.20 (GND), J2.25 (GND), J2.30 (GND), J2.34 (GND), J2.39 (GND), J3.3, J4.3, J5.3, J7.4, J8.2, J8.4, J8.6, J8.8, J9.4, J10.3, J11.3, MOD1.3 (GND), Q3.2 (E), SW1.2, U1.19 (GND), U1.39 (GND), U2.3 (GND)
GPIO-13: J2.33 (GPIO13), J8.5, R11.1
GPIO-16: J2.36 (GPIO16), J8.3, R10.1
GPIO-17: J2.11 (GPIO17), U1.1 (PB12)
GPIO-20: J2.38 (GPIO20), J8.1, R4.1
GPIO-26: J2.37 (GPIO26), J8.7, R12.1
LRCK: J2.35 (GPIO19), J9.3
NEO-0: Q2.2 (S), R7.1, U1.11 (PB3)
NEO-1: Q1.2 (S), R6.1, U1.12 (PB4)
unnamed: J2.10 (UART0_RX), U1.6 (PA9)
unnamed: J2.08 (UART0_TX), U1.7 (PA10)
unnamed: J3.2, R3.2
unnamed: J10.2, R9.2
unnamed: J11.2, U2.4
unnamed: JP1.2 (C), R2.2
unnamed: LS1.2 (GND), Q3.3 (C)
unnamed: Q1.3 (D), R3.1, R5.1
unnamed: Q2.3 (D), R8.1, R9.1
unnamed: Q3.1 (B), R2.1
RC-PWM-0: J5.2, U1.5 (PA8)
SBUS: J2.29 (GPIO05), U2.2
SCL: J2.05 (GPIO03/SCL), MOD1.4 (SCL)
SCL_MCU: J7.3, U1.14 (PB6)
SDA: J2.03 (GPIO02/SDA1), MOD1.5 (SDA)
SDA_MCU: J7.2, U1.15 (PB7)
TFT-CS: DISP1.3 (CS), U1.36 (PB2)
TFT-DC: DISP1.5 (DC/A0), U1.34 (PB0)
TFT-MOSI: DISP1.6 (MOSI), U1.33 (PA7)
TFT-RESET: DISP1.4 (RST), U1.35 (PB1)
TFT-SCK: DISP1.7 (SCK), U1.31 (PA5)

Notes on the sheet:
Buzzer Active or Passive
AUDIO DAC
AUX
Buttons
FrSky Receiver
FOOT CONTACTS
NeoPixel
I2C AUX
RC-Servo
5vDC Power In Isolated DC-DC

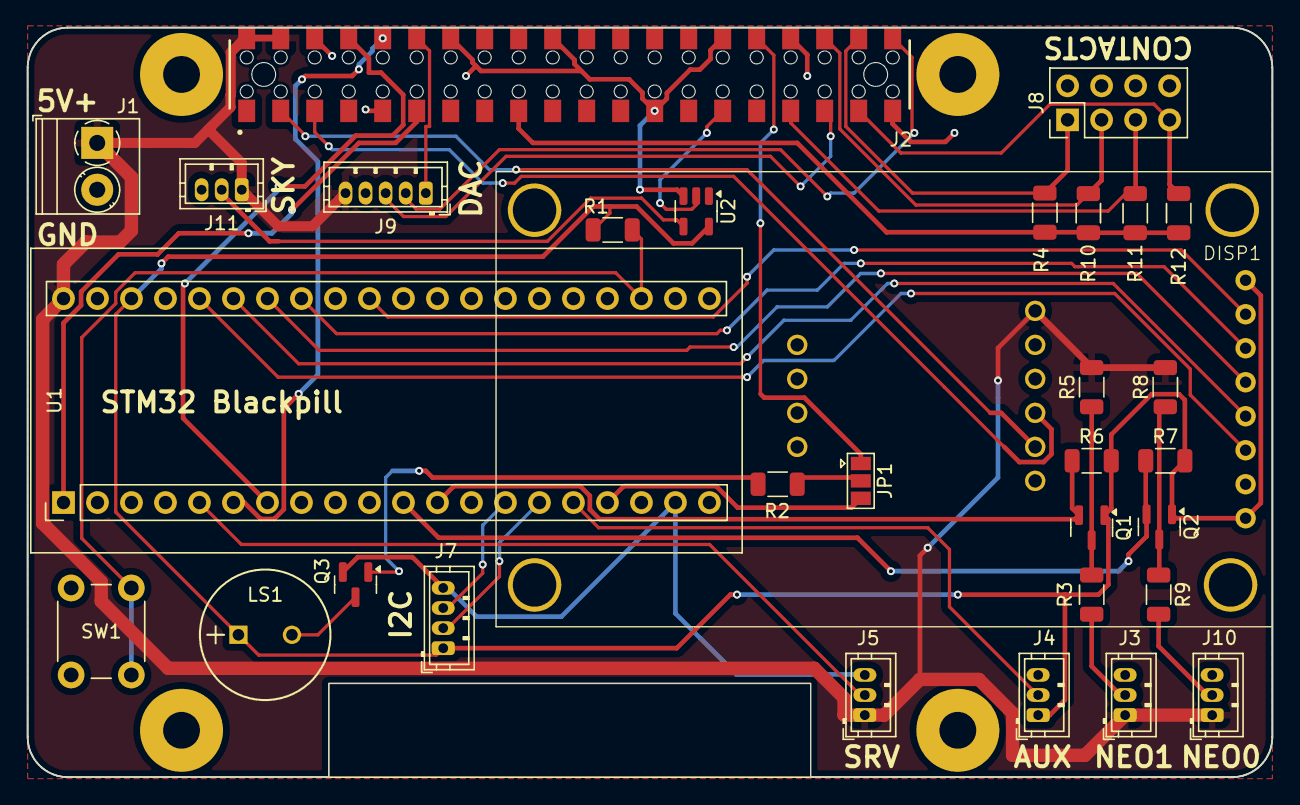
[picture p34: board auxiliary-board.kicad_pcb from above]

Board: 2 copper layers, 93.0 x 56.0 mm, 32 parts (1 on the bottom side), 39 nets.

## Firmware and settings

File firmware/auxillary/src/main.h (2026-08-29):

///////////////////////////////////////////////////////////////////////////////
// Pins
///////////////////////////////////////////////////////////////////////////////

#define PIN_BTN_1 PC14
#define PIN_RPI_HEARTBEAT PB12
#define PIN_MCU_BUZZER PB9
#define PIN_NEO_0 PB3
#define PIN_NEO_1 PB4

///////////////////////////////////////////////////////////////////////////////
// Timings
///////////////////////////////////////////////////////////////////////////////

const uint32_t heartbeatBlinkRateMs{250};
const uint32_t noCommsTimeoutMs{1000};
const uint32_t rpiHeartbeatTimeoutMs{250};
const uint32_t byteLongPressActivationMs{3000};

///////////////////////////////////////////////////////////////////////////////
// General
///////////////////////////////////////////////////////////////////////////////

const float gamepadLowBatteryPercentThreashold{0.25};
const float systemLowBatteryPercentThreashold{0.25};

///////////////////////////////////////////////////////////////////////////////
// Display
///////////////////////////////////////////////////////////////////////////////

enum class Page
{
    SPLASH,
    SYSTEM,
    BATTERY
};

const int numSystemStatus{12};
const char *systemStatusStrings[numSystemStatus] = {"RPI", "SFT", "JOY", "LIM", "JA", "IK", "CAN", "OTe", "UVo", "MCo", "IMU", "BAT"};
const char *motorStatusStrings[] = {"FLA", "FLH", "FLK", "FRA", "FRH", "FRK", "BLA", "BLH", "BLK", "BRA", "BRH", "BRK"};

///////////////////////////////////////////////////////////////////////////////
// Message and Data Structs
///////////////////////////////////////////////////////////////////////////////

bool systemErrors[numSystemStatus];

const int numMotors{12};
bool motorOns[numMotors];
bool motorErrors[numMotors];

struct SystemValues
{
    float batteryVoltage{0};
    float joystickBatteryPercentage{0};
} systemValues;

#pragma pack(1)
struct StatusData
{
    bool joystickError;
    bool physicalLimitError;
    bool jointAngleError;
    bool inverseKinematicsError;
    bool canError;
    bool overTemperatureError;
    bool underVoltageError;
    bool motorCommunicationError;
    bool imuError;
    bool lowBattery;

    bool motorOns[numMotors];
    bool motorErrors[numMotors];

    float batteryVoltage;
    float joystickBatteryPercentage;
};

enum class MessageType : uint8_t
{
    STATUS = 0,
    PLAY_SOUND,
    SHUTDOWN_RPI
};

#pragma pack(1)
struct StatusMessage
{
    MessageType messageType;
    StatusData statusData;
    uint32_t crc32;
};

#pragma pack(1)
struct PlaySoundMessage
{
    MessageType messageType;
    uint8_t sequenceId;
    uint32_t crc32;
};

#pragma pack(1)
struct ShutDownMessage
{
    MessageType messageType;
    uint32_t crc32;

    ShutDownMessage()
    {
        messageType = MessageType::SHUTDOWN_RPI;
    }
};

///////////////////////////////////////////////////////////////////////////////
// Prototypes
///////////////////////////////////////////////////////////////////////////////

void InitDisplay();
void UpdateDisplay(bool forceRefresh);
void DisplaySplashPage();
void DisplaySystemPage(bool forceRefresh);
void DisplayBatteryPage(bool forceRefresh);

bool IsLowBattery();
bool IsError();

///////////////////////////////////////////////////////////////////////////////
// Helpers
///////////////////////////////////////////////////////////////////////////////

// TODO: an assert of other warning should be applied of the string is not found.

int getIndexFromStatusString(const char *status)
{
    for (int i = 0; i < numSystemStatus; i++)
    {
        if (strcmp(status, systemStatusStrings[i]) == 0)
        {
            return i;
        }
    }
    return -1;
}

int getValueFromStatusString(const char *status)
{
    int index = getIndexFromStatusString(status);

    if (index != -1)
        return systemErrors[index];
    else
        return false;
}

void setValueFromStatusString(const char *status, bool state)
{
    int index = getIndexFromStatusString(status);

    if (index != -1)
        systemErrors[index] = state;
}

///////////////////////////////////////////////////////////////////////////////
// CRC
///////////////////////////////////////////////////////////////////////////////

uint32_t crc32(uint8_t *data, int length)
{
    const uint32_t POLYNOMIAL = 0x04C11DB7;
    uint32_t crc = 0xFFFFFFFF;

    for (size_t i = 0; i < length; i++)
    {
        crc ^= data[i] << 24;
        for (int j = 0; j < 8; ++j)
        {
            if (crc & 0x80000000)
            {
                crc = (crc << 1) ^ POLYNOMIAL;
            }
            else
            {
                crc <<= 1;
            }
            crc &= 0xFFFFFFFF;
        }
    }
    return crc ^ 0xFFFFFFFF;
}

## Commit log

2026-08-14 import upstream micromouse project: kicad pcb, symbols, footprints, firmware, sim, docs
    [BOM.xlsx, MiceyMousey.kicad_pcb, MiceyMousey.kicad_sch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]
2026-08-14 remove duplicate nested footprint library
2026-08-14 add readme with features, BOM, images and build steps
2026-08-28 add pcbs folder
2026-08-29 Add Light-Doggo project files
    [assembly-v20.step, auxiliary-board.kicad_pcb, auxiliary-board.kicad_sch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]
2026-08-29 Added the bom.csv
    [bom.csv]
2026-09-04 Add laptop and additional tools to BOM
    [bom.csv]
2026-09-04 Add additional tools to BOM
    [bom.csv]
